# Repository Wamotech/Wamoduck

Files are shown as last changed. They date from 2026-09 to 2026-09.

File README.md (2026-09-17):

<p align="center">
  <a href="https://www.wamotechology.com">
    <picture>
      <source media="(prefers-color-scheme: dark)" srcset="assets/branding/wamotech-symbol-white.png">
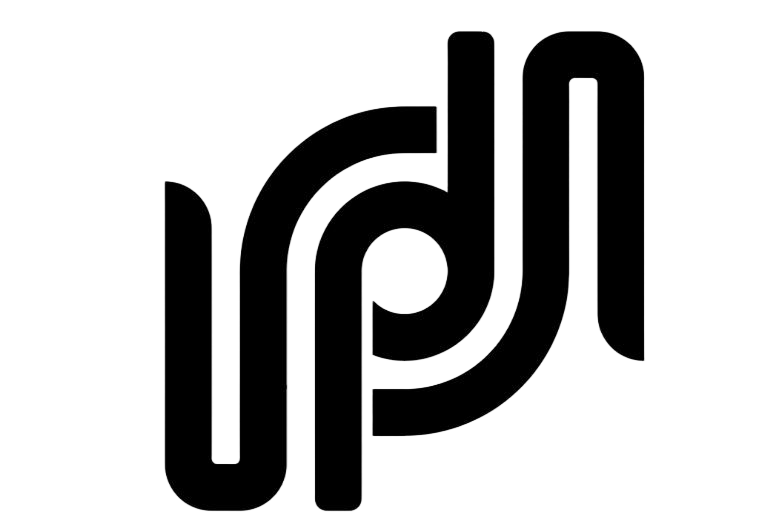
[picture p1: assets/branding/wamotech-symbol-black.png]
Wamotech logo
      
    </picture>
    <br>
    <picture>
      <source media="(prefers-color-scheme: dark)" srcset="assets/branding/wamotech-wordmark-white.png">
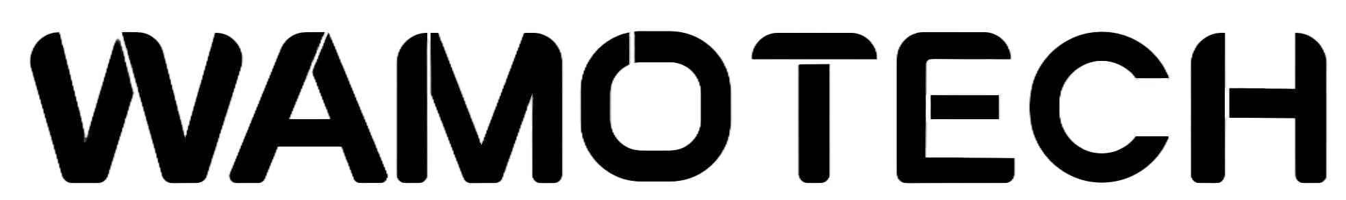
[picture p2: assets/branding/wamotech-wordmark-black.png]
WAMOTECH
      
    </picture>
  </a>
</p>

# Wamoduck

**An expressive little duck. A platform to explore motion, perception, and autonomous behavior.**

English | [简体中文](README.zh-CN.md)

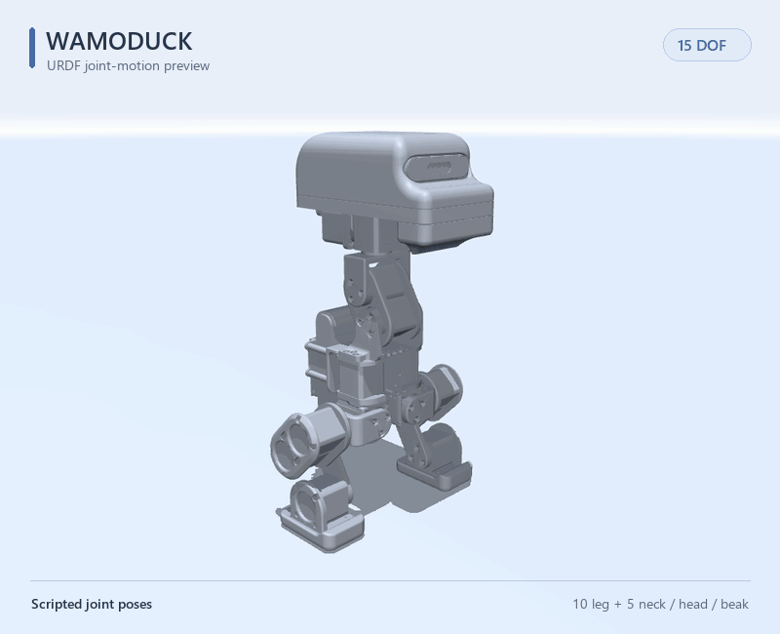
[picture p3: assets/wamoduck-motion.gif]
Wamoduck URDF joint-motion preview


*Rendered from the Wamoduck URDF. This scripted joint-motion preview illustrates articulation; it is not hardware footage or an ONNX policy rollout.*

## What this is

Wamoduck is a **15-DOF open-source biped duck robot**. Wamotech builds it as a small, approachable
platform for experimenting with motion, perception, and autonomous behaviour.

The project is in **mechanical prototyping and hardware/software integration**. The MuJoCo simulation
work is finished. The physical robot is still being assembled and debugged.

This repository is the public slice of that work. It gives you four things:

- the **CAD, URDF, and meshes** of the robot,
- a **reference walking gait** with a MATLAB player,
- **five trained policies** you can run yourself, in about five minutes,
- print files for a **standing fixture** and a small **display model**.

> ### Read this before you quote anything from here
>
> **Every result in this repository is a simulation result.** There is no hardware data anywhere in it,
> and no policy in it has ever been tested on a physical robot. "It stands in MuJoCo" is not a claim
> that it stands on the real machine.

**The quickest way in** is to run the policies. No GPU, no training framework, no MuJoCo experience.

## What it can do today, and what it cannot

Six behaviours were trained and measured in simulation on **2026-09-16**. Five of them ship here as ONNX
files you can run on your own machine.

| What it does | Policy | Measured result (simulation) |
| --- | --- | --- |
| Stands still, and takes a shove | `stand_v3` | Push threshold **40.5 N** — the smallest single horizontal 0.2 s shove that topples at least half of 64 environments. 40 N topples 45.3 % of them, and 0 to 24 N topples none. |
| Knocked down → gets up → back to the nominal stance | `stand_v3` + `getup_v20` | **5/5** end-to-end trials. "Did not fall again after standing up": **5/5**. |
| Gets up from a random lying pose | `getup_v20` | Standing at the end: **64/64**; strict "back to the saved nominal pose" **63/64 (98.4 %)** — up from **0/64**, with the largest joint deviation down from **52.3°** to **10.4°**. |
| Walks on flat ground | `walk_v4r` | Forward walking works. **Side-stepping does not**, and **in-place turning is out of reach for this mechanism** — a measured limit, not an unfinished training round. |
| Walks over 1 cm rough terrain | `rough_v2` | **51/64 (79.7 %)** survive 12 s at a 0.3 m/s command. Mean speed is **61 %** of the command. |
| Sits down and stands back up | `sit_stand_v3` | Interactive height control, and the two issues reported on the previous policy are **fixed**: standing jitter **0.699 → 0.000** and net drift **+27.99 → +0.394 mm/s**; the sitting pose goes from a **10.05°** lean with **146.09°** of left/right asymmetry to **0.225°** with a **0.473°** asymmetry. The seat is **0.11241 m** — 0.085 m is geometrically unreachable with an upright trunk. |

### What still does not work

- **In-place turning is out of reach for this mechanism, not merely untrained.** A 0.5 rad/s yaw command produced **+0.3°** of rotation in 10 s. Measured on plain CPU MuJoCo with both feet planted: the hips' yaw joints are an internal torque pair, so they can only twist the torso **±30.5°** relative to the ground, and unloading one foot would need a **60 mm** sideways CoM shift while the design can produce **38.5 mm** — at which point it is already tilted **28.5°** against a **30°** fall line. Eleven planted-foot drive patterns were tried; none accumulates. Measured with the published policy through the published runner, it **does not walk at all below 0.20 m/s** (0.012–0.018 m in 10 s at 0.10–0.15 m/s) and above that it turns **while moving** — 62 % / 69 % / 75 % of a 0.5 rad/s command at 0.20 / 0.30 / 0.40 m/s, on arcs of measured radius 0.72 / 0.93 / 1.11 m. The capability board therefore restates the deliverable as **turning while moving (tightest measured arc R ≈ 0.7 m at vx ≥ 0.20 m/s)** and lists true in-place rotation as a **hardware** change — see [Why in-place turning cannot be trained away](docs/capabilities.md#why-in-place-turning-cannot-be-trained-away).
- **Side-stepping drags the robot round.** A +0.30 m/s sideways command produced +0.218 m/s sideways
  *and* **+520.4°** of uncommanded yaw. Our own CPU run shows a small version of the same thing: over
  5 s of straight-ahead walking it drifted **0.328 m** sideways.
- **Get-up's "back to the nominal pose" gap was fixed on 2026-09-16.** On the **previous** policy
  (`getup_v18`, still published) it got up and stood reliably — 64/64 — but the strict criterion "back to the
  saved nominal pose" was **0/64**, with the error concentrated in the second link of the head chain
  (**52.3°** of joint deviation, and a sustained-900-step acceptance that stopped at `head_pitch` **46°**).
  The replacement `getup_v20` measures **63/64** on that strict criterion, **10.4°** of joint deviation, and
  **5/5** on the end-to-end hand-over. What changed was one reward term: the head-chain posture penalty is
  **ungated** and now weighs **−1.0**; gating it by body tilt — the previous round's change — let the policy
  escape through the gate by staying tilted, and it collapsed to **0/5** on the hand-over.
  The stricter six-axis criterion (head off the ground, flat soles, each sustained over the last second) is
  **45/64**, up from **0/64**.
- **Sit/stand was fixed on 2026-09-16, and the two problems remain on record with the measurements that
  found them.** On the **previous** policy (`sit_stand_v2`, still published): switching to `sitstand` made
  the robot **buzz in place while standing** — action jitter `mean abs(delta a)` per control step **0.235**
  at the 0.175 m command, against **2.9e-7** for `stand`, with **1.69 rad/s** of mean joint velocity that
  never decayed — and asking it to **sit** produced a **25.89°** lean (head **25.62°** off vertical) at
  **0.0943 m** instead of the 0.085 m commanded, resting partly on its own pelvis, with the left and right
  legs on opposite sides of zero on three of the five leg pairs (residuals **119°** to **174°**). The
  replacement policy `sit_stand_v3` measures **0.000** jitter, **+0.394 mm/s** of drift, and a sitting pose
  that is **0.225°** off vertical with a **0.473°** left/right residual — see [row 6 of the capability
  board](docs/capabilities.md#6-sit--stand). One limitation arrives with it: **the seated pose is not a
  stance the walking policy can start from** (tilt 134.9° after 6 s), so stand up with `m` before walking.
  Note also that the seat moved from 0.085 m to **0.11241 m**, because 0.085 m is geometrically unreachable
  with an upright trunk.
- **There is no hardware data at all.** Nothing in this repository was measured on a physical robot.

These are the parts we would rather state than let you discover. The full protocols, the tools behind
every figure, and the exact definition of "standing" are on the
[measured capability board](docs/capabilities.md) / [实测能力清单](docs/capabilities.zh-CN.md).

## Try it in 5 minutes

```bash
pip install mujoco onnxruntime numpy

git clone <this repository>
cd Wamoduck
python wamoduck_sim.py
```

One window opens, and all five policies run inside it. Press a number key to switch — and the window itself
tells you what the current policy does and which keys work for it, in plain words and in both languages:

| Key | Policy | What you should see |
| --- | --- | --- |
| `1` | `stand` — 站立抗推 | Standing still. Drag it with the mouse and it finds its balance again. |
| `2` | `getup` — 起身 | Starts lying on the ground, then stands up **and settles into the nominal pose**. |
| `3` | `sitstand` — 坐下与站起 | Press `m` to sit down (0.11241 m) and again to stand back up. |
| `4` | `walk` — 平地行走 | Arrow keys (or `w` `a` `s` `d`) drive it; `e` and `z` turn. Below 0.20 m/s it does not walk. |
| `5` | `rough` — 越障行走 | The same walking, over 1 cm curbs. It starts on three of them. |

The version handle (`getup_v20`, `sit_stand_v3`, …) is shown next to the plain name: it is what ties the file
you are running to a checkpoint, a hash and a changelog entry. Top-left in the window you get the policy, the
version, the keys that do something *for that policy*, and a suggested thing to try; bottom-left, the live
command values.

The runner needs only `mujoco`, `onnxruntime`, and `numpy` — no mjlab, no torch, no CUDA. A few useful
flags:

```bash
python wamoduck_sim.py --list                    # what is published
python wamoduck_sim.py --policy walk --vx 0.3    # start on walking at 0.3 m/s
python wamoduck_sim.py --policy getup --spawn lie-back
python wamoduck_sim.py --policy stand --check    # contract self-test, no window
```

**What our own CPU runs measured, through this same published code path:** `stand` holds **0.54°** of
tilt and 1 mm of drift over 5 s — good enough to pass even the strict nominal-stance criterion; `getup`
stands up from all five published lying poses within 6 s; and `walk` covers **1.482 m** of a commanded
**1.500 m** at 0.3 m/s.

Before you use the files, read the [simulation guide](docs/simulation.md) / [中文仿真指南](docs/simulation.zh-CN.md).
It writes out the observation layout and the action mapping item by item, explains why the ONNX already
contains the observation normalizer, explains why you **must** use the bundled MJCF and not the URDF, and
lists the known gaps.

## There is also a ROS 2 path

If you would rather not touch a physics engine, [`ros2/`](ros2/README.md) is a second way in. It is a
ROS 2 **Jazzy** chain for the same robot: the description loads in RViz, the reference gait replays as
`sensor_msgs/JointState`, and the 46-byte deployment protocol ships with a unit-tested, ROS-free codec.

Stage 1 (packages) and stage 2 (RViz visualisation) are built and verified. Read the
[ROS 2 guide](ros2/README.md) / [中文版](ros2/README.zh-CN.md) for the commands.

**What that path does not claim:**

| Area | State |
| --- | --- |
| Machine | Verified only on **WSL2 Ubuntu 24.04, x86_64**. Nothing has been built or run on the RDK X5's ARM64 userspace, so availability there is **unverified**. |
| Hardware | **Not verified.** No serial port, no CAN bus, no motors, no IMU. The protocol's `serial` transport has never been opened. |
| `policy_node` end to end | **Not run.** It is a skeleton: it assembles observations and never infers, because `onnxruntime` is not installed. |
| Gazebo and MoveIt | **Not started.** Nothing in `ros2/` runs Gazebo. |
| Physics | RViz integrates nothing and applies no gravity, so a gait that looks plausible on screen has proven nothing about dynamics or balance. **MuJoCo remains the physics reference for this project.** |

## Other ways to explore

### Try the reference gait in MATLAB

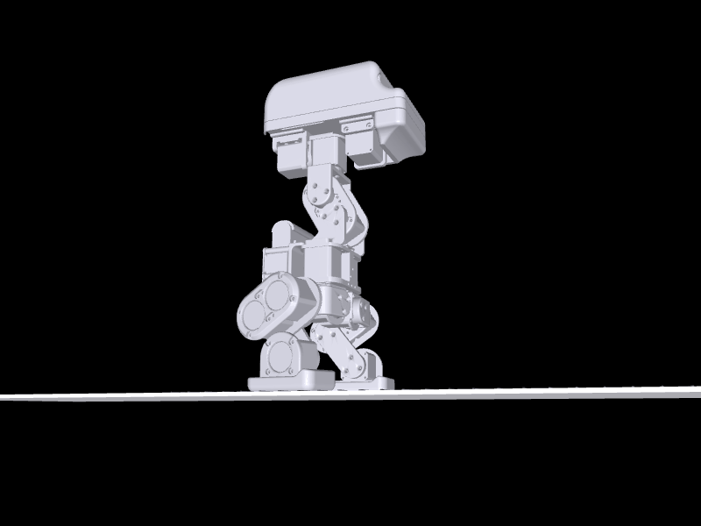
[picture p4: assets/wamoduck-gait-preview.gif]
Wamoduck walking reference gait


*Reference quasi-static gait, replayed from the public URDF by prescribing the joint angles in [tools/matlab/data/](tools/matlab/data/) and running forward kinematics. It is a plan, not a trained policy and not hardware footage.*

A walking reference trajectory for this URDF is included, together with a MATLAB player:

```matlab
cd <repo>              % the folder containing models/ and tools/
addpath('tools/matlab')
wamoduck_play          % interactive player
wamoduck_play(true)    % headless self-test: units, joint limits, ground contact
```

The player steps through the data, plots all 15 joint torques against the motor's rated and peak values,
and shows a per-joint angle/torque table. Two data sets ship with it: one steady-state gait cycle
(2.0 s, loops seamlessly) and the full 1 m walk.

The published CSV files contain model-computed joint angles and torque estimates. Their largest absolute
torque is **2.50815 N·m**, at the right knee in the full walk. The original higher-rate planner and its
IK/dynamics generation code are not included; see the [gait guide](docs/matlab.en.md) for the difference
between reproducible CSV checks and reported planning results.

The reference trajectory uses small alternating foot lifts. Its model-based playback does not establish
dynamic balance. The separate planning analysis identified limited lateral centre-of-mass travel and the
absence of an ankle roll; see the [gait guide](docs/matlab.en.md) for its scope and known limits.

### Print something

- The [standing calibration fixture](hardware/fixtures/standing-zero/README.md) has four printable parts,
  a two-plate H2D PLA project, six M3 screw specifications, and fitting instructions. Its digital
  geometry has been checked; **physical print fit and repeatability are still unmeasured**.
- The [160 mm A1 mini figurine](hardware/printable/wamoduck-a1mini-standing/README.md) is a separate
  single-piece display model.

### Open the CAD or the model

- [20 simplified STEP part models](hardware/step/) and the [native SolidWorks assembly](hardware/solidworks/)
  ([opening instructions](docs/mechanical.en.md#solidworks-assembly)).
- The [URDF and its meshes](models/wmduck/), with the [model guide](docs/model.en.md) for joint names,
  axes, and limits.
- The [component inventory](docs/components.md) for what the model actually contains.

Download or clone the complete repository before opening an assembly or URDF: those files need the parts
or meshes supplied alongside them.

### Wire it up

- The [CAN-FD bus IDs](hardware/motor_ids.md) of all 15 motors, with the position drawing, the three buses
  behind them, and the permutation from the policy's action vector to those IDs. The page also says plainly
  that the permutation and the bus topology have **not** been verified on the physical robot.

## Where to go next

| I want to… | Open |
| --- | --- |
| **Run the trained policies myself in MuJoCo** | [Simulation guide](docs/simulation.md) · [ONNX policies](policies/) · [`wamoduck_sim.py`](wamoduck_sim.py) |
| **Use ROS 2 instead of MuJoCo** | [ROS 2 guide](ros2/README.md) |
| See what the trained policies can actually do, and what still fails | [Measured capabilities](docs/capabilities.md) |
| Inspect or adapt individual mechanical parts | [20 STEP models](hardware/step/) · [Mechanical guide](docs/mechanical.en.md) |
| Print the standing calibration fixture | [Four parts + H2D PLA project](hardware/fixtures/standing-zero/README.md) · [Quantities](hardware/fixtures/standing-zero/print-parts.csv) |
| Print a small static display model | [160 mm A1 mini figurine](hardware/printable/wamoduck-a1mini-standing/README.md) |
| Look up a CAN-FD bus ID, or wire the three buses | [Bus IDs and the position drawing](hardware/motor_ids.md) |
| Explore the native assembly | [SolidWorks files](hardware/solidworks/) · [Opening instructions](docs/mechanical.en.md#solidworks-assembly) |
| View the robot and inspect its joints | [URDF and meshes](models/wmduck/) · [Model guide](docs/model.en.md) |
| Watch the reference gait / play with it in MATLAB | [Gait guide](docs/matlab.en.md) · [MATLAB player](tools/matlab/) · [Walk video](assets/wamoduck-gait-walk.mp4) |
| Understand the modeled components | [Component inventory](docs/components.md) |
| Help improve the project | [Contributing](CONTRIBUTING.md) · [Roadmap](docs/roadmap.md) |

## The robot itself

| Feature | What it enables |
| --- | --- |
| **Servo-based closed-loop control** | Motor feedback closes the loop between motion commands and execution, providing a basis for motion tracking and hardware tuning. |
| **A low-level “cerebellum” and a higher-level “brain”** | A 32-bit MCU handles low-level robot control, while an Arm-based computer supports ROS and ONNX policy inference. This separates motor control from higher-level perception and behavior. |
| **Onboard visual perception** | A binocular structured-light camera supplies visual and depth information for local scene recognition and spatial modeling. |
| **An extensible structure** | The mechanical design leaves room to adapt structures, sensors, and peripherals as experiments evolve, alongside changes to the computing and control stack. |

### System architecture

```mermaid
flowchart LR
    Remote[Remote-control commands] --> Brain["Arm brain<br/>ROS · ONNX policies<br/>Perception and behavior"]
    Camera["Binocular structured-light camera<br/>Visual and depth data"] --> Brain
    Brain <-->|Motion targets / state feedback| MCU["32-bit MCU cerebellum<br/>Low-level robot control"]
    MCU <-->|Commands / motor feedback| Servo[Servo motors]
```

This architecture is also being experimentally applied to **intelligent wearable robot projects**, exploring how control, perception, and policy components can be reused across different robot forms.

### 15 joints, from footsteps to expression

The finalized URDF describes **15 rotational DOF = 5 left-leg + 5 right-leg + 5 neck/head/beak**:

| Group | DOF | Joint sequence |
| --- | ---: | --- |
| Left leg | 5 | Hip yaw → hip roll → hip pitch → knee → ankle |
| Right leg | 5 | Hip yaw → hip roll → hip pitch → knee → ankle |
| Neck, head, and beak | 5 | Neck pitch → head pitch → head yaw → head roll → mouth |

The neck contributes 1 DOF, the head 3, and the beak 1. Together they allow expressive nods, turns, tilts, and beak movements in addition to the two leg chains.

There are **17 links**: 16 mechanical rigid bodies plus 1 fixed IMU reference link. The IMU reference does not add an actuated DOF. The saved standing pose is `q=0`, with bent legs and an inclined neck; it is not the motor encoder zero. See the [model guide](docs/model.en.md) for exact joint names, axes, and limits, and the [animation notes](assets/README.md) for how the preview was made.

<details>
<summary>Explore the 15 joint origins in four views</summary>

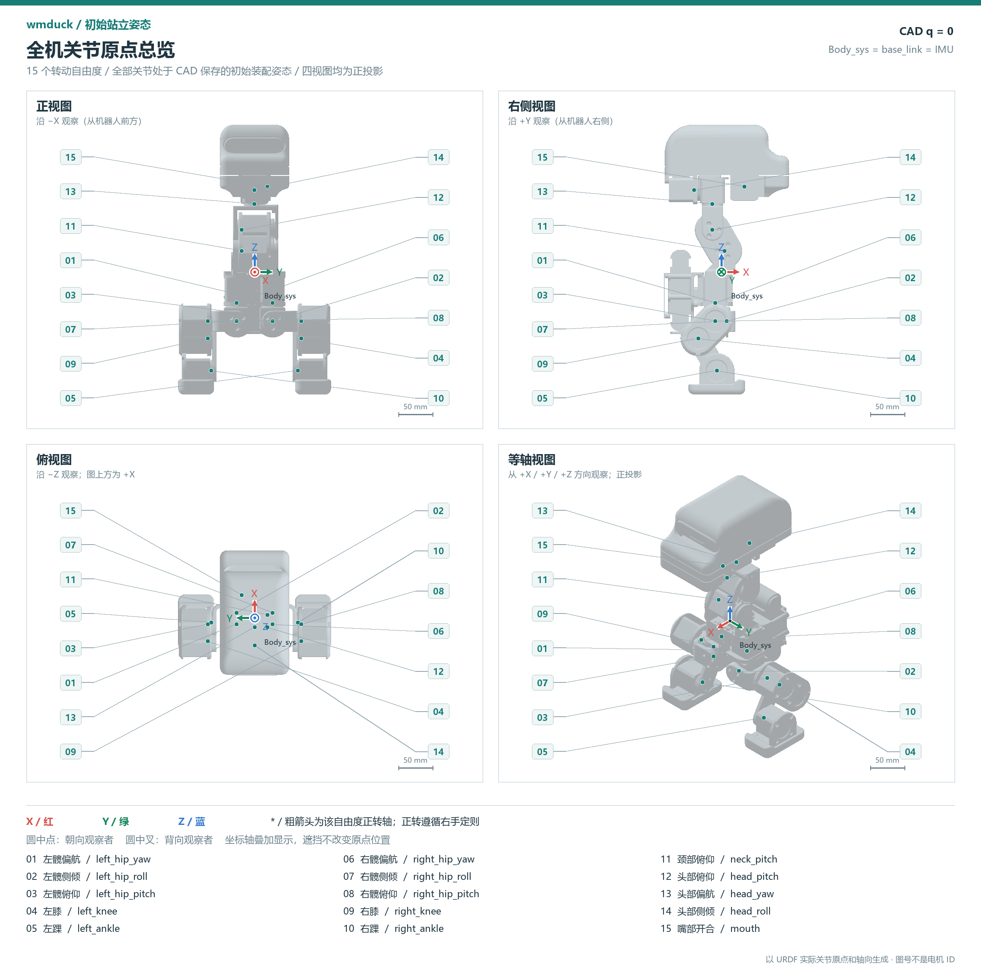
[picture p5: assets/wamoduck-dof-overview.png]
Final URDF joint-origin overview: front, right, top, and isometric views


Orthographic views of the finalized URDF at the saved `q=0` pose. Labels 01–05 identify the left leg, 06–10 the right leg, 11 the neck, 12–14 the head, and 15 the beak. These labels are diagram indices, not motor IDs. Red, green, and blue mark X, Y, and Z; the joint-name legend is included in the image.

</details>

## At a glance

| Item | Current model |
| --- | --- |
| Rotational joints | 15: left leg 5 + right leg 5 + neck/head/beak 5 |
| Robot description | URDF; 16 mechanical links + 1 fixed IMU reference link |
| Geometry | 20 simplified STEP part models; 20 STL meshes for the URDF |
| Approximate model envelope at the saved pose | 181.5 × 221.2 × 390.8 mm (X × Y × Z) |
| Estimated model mass | 3.751 kg; CAD values with a measured motor mass override, not a measured robot weight |
| Head-chain share of that mass | 1.654 kg = 44.1 %: `neck_pitch_link` through `mouth_link` |
| Model units | m, kg, rad; STEP files declare mm |

The mass and envelope describe the supplied model, not certified hardware specifications. See the [model assumptions](docs/model.en.md) before using its inertias, motor values, or joint ranges.

The behaviour table near the top of this page is a different kind of number: those rows are simulation
results for the trained policies, measured on 2026-09-16 in the private development environment. They are
**not hardware measurements.** Five of the policies are now published with a runner, so their behaviour
can be re-run here in simulation — see the [simulation guide](docs/simulation.md) for exactly what is and
is not reproducible — but the internal measurement protocols and tools are still private.
See [measured capabilities](docs/capabilities.md) for the methods, the tools, and the parts that do not work.

The bundled [validation record](models/wmduck/validation.json) covers this URDF package's structural and
import checks. It is not a validation of the project's simulation or of a physical robot.

## What is included

```text
Wamoduck/
├── hardware/
│   ├── step/             # Robot structure and purchased-component references, mm
│   ├── solidworks/       # Simplified native parts and assemblies
│   ├── robot-structure.csv # Geometry roles and modeled instance quantities
│   ├── motor_ids.md      # CAN-FD bus IDs, the three buses, and the action permutation
│   ├── fixtures/standing-zero/ # 4 STEP + 4 printable STL + H2D project
│   └── printable/        # Static display model and A1 mini project
├── models/wmduck/        # URDF, meshes, joint data, and import checks
│   └── mjcf/             # The MJCF models the policies were trained on
├── policies/             # Five trained ONNX policies
├── wamoduck_sim.py       # Single-file CPU runner: one demo, all five policies (mujoco + onnxruntime + numpy)
├── ros2/                 # ROS 2 Jazzy chain: description, nodes, RViz, the 46-byte protocol
├── tools/matlab/         # Reference-gait data and the MATLAB player
├── assets/              # Model preview, gait preview, and the motor-ID drawing
├── docs/                # Bilingual guides: mechanical, model, gait, simulation, capabilities, roadmap
├── CONTRIBUTING.md
└── LICENSE
```

Robot STEP files support geometry exchange and slicing of the selected structural geometry. The [manufacturing map](hardware/robot-structure.csv) distinguishes structural parts from motors, bearings, and electronics supplied as assembly references. The STL files under `models/wmduck/meshes/` use meters for robot visualization and collision; use the millimeter STL files in [the fixture package](hardware/fixtures/standing-zero/README.md) to print the jig. Joint limits are estimates from single-joint geometry checks and do not guarantee collision-free combined motion.

## What this repository does not contain yet

The simulation and training code, the checkpoints behind the measured results and their evaluation tools,
the runtime software, the electronics, and a complete build guide are **not** published here. Neither is a
verified procurement BOM, structural manufacturing specification, assembly instruction, wiring diagram, or
control software.

A complete working robot needs all of those. The [roadmap](docs/roadmap.md) tracks them as deliverables.

## Build along with us

Interested in servo control, robot perception, policy deployment, or your own mechanical variation? **Star the project to follow its progress**, share ideas through Issues, or contribute improvements through a pull request. Contributions in English and Chinese are welcome; start with the [contribution guide](CONTRIBUTING.md).

We will keep publishing mechanical revisions, integration progress, and software and hardware documentation as the project develops. Follow the [roadmap](docs/roadmap.md) for the next steps.

## Contact

- Email: [business@wamotechology.com](mailto:business@wamotechology.com)
- Website: [www.wamotechology.com](https://www.wamotechology.com)

## References and license

The documentation structure draws on [Open Duck Mini](https://github.com/apirrone/Open_Duck_Mini) and [Pollen Robotics Microduck](https://github.com/pollen-robotics/microduck): accessible design files, clear model assumptions, and separate build/runtime/training instructions. The ONNX deployment approach is similar in spirit to [Microduck](https://github.com/pollen-robotics/microduck) and [microduck_rl](https://github.com/pollen-robotics/microduck_rl). See [references and scope](docs/references.md) for the exact sources and distinctions.

This repository retains its existing [MIT license](LICENSE), copyright © 2026 Wamotech. Referenced projects and third-party components retain their own licenses and rights. Their dimensions, controllers, and build instructions should not be assumed compatible with Wamoduck.

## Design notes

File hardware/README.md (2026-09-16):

# Mechanical design / 机械设计

[English guide](../docs/mechanical.en.md) · [中文指南](../docs/mechanical.zh-CN.md)

[Static display prints / 固定展示打印模型](printable/README.md): a separate 160 mm A1 mini figurine, with fused joints and an integral base. / 独立的 160 mm A1 mini 摆件，关节固定并带一体底座。

- [step/](step/): 20 simplified millimetre STEP geometries: 15 robot-structure classes and 5 purchased/reference classes. See [robot-structure.csv](robot-structure.csv). / 20 类毫米单位 STEP 简化几何：15 类机器人结构几何与 5 类外购／参考几何，分类见 [robot-structure.csv](robot-structure.csv)。
- [solidworks/](solidworks/): 20 parts and 11 assemblies; start with `Full_wmduck.SLDASM`. / 20 个零件与 11 个装配体，入口为 `Full_wmduck.SLDASM`。
- [fixtures/standing-zero/](fixtures/standing-zero/): downloadable standing-zero calibration fixture with [English](fixtures/standing-zero/README.md) and [中文](fixtures/standing-zero/README.zh-CN.md) instructions. It contains four editable STEP files, four millimetre-scale print STL files, and a user-supplied Bambu H2D 3MF arranged on two plates. Print one of each part; assembly uses six M3 screws. / [站姿零点标定工装](fixtures/standing-zero/)提供[英文](fixtures/standing-zero/README.md)与[中文](fixtures/standing-zero/README.zh-CN.md)说明，包含 4 个可编辑 STEP、4 个毫米单位打印 STL，以及用户提供的双盘 Bambu H2D 3MF。每种零件打印 1 件，共使用 6 颗 M3 螺钉。
- [motor_ids.csv](motor_ids.csv) with [English](motor_ids.md) and [中文](motor_ids.zh-CN.md) notes: the CAN-FD bus ID of each of the 15 motors, which of the three buses (left leg, right leg, neck and head, each on an XT30(2+2) connector carrying power and CAN-FD) that motor sits on, and the permutation from the policy's 14-dimension action vector to those IDs. Bus IDs, joint names, and orders are interface facts; the page carries a prominent warning that the permutation and the bus topology are unverified on the physical robot. / [motor_ids.csv](motor_ids.csv) 及[英文](motor_ids.md)、[中文](motor_ids.zh-CN.md)说明：15 个电机各自的总线 ID、它挂在哪一路总线（左下肢、右下肢、脖子及头部，每路用承载电源与 CAN-FD 的 XT30(2+2) 端子），以及从策略 14 维动作向量到这些 ID 的置换。总线 ID、关节名与顺序都是接口事实；该页醒目地警告：置换与总线拓扑均未在实机上验证。

The 20 robot STEP/native files provide geometry and assembly references; their assembly instance counts do not define printable part splits. `Body_Frame` may import as multiple bodies, and CAD material labels are model metadata rather than manufacturing requirements. Manufacturing and clean-session native dependency validation for the robot are still pending. The zero fixture has passed the documented CAD/STL checks, but no physical print or repeatability test is claimed. / 这 20 类机器人 STEP／原生文件用于几何和装配参考；装配实例数量不等于打印分体数量。`Body_Frame` 导入后可能包含多个实体，CAD 材料标签属于模型元数据，不是制造要求。机器人制造要求及原生装配在独立会话中的依赖验证仍待补齐。零点工装已通过文档所列 CAD／STL 检查，但不宣称已经完成实物打印或重复定位测试。

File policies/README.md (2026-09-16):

# Wamoduck policies / 策略权重

[English simulation guide](../docs/simulation.md) · [中文仿真指南](../docs/simulation.zh-CN.md)

Five trained tasks, and six ONNX actors: the sit/stand row carries **two** files, because the 2026-09-16
replacement is published next to the file whose measured problems it fixes. Each is an ONNX actor for one
task; run them with [`wamoduck_sim.py`](../wamoduck_sim.py) and the MJCF in
[`models/wmduck/mjcf/`](../models/wmduck/mjcf/). / 五个训练任务、**六个** ONNX actor：坐／站那一行有**两份**
文件 —— 2026-09-16 的替换版本与"被它修掉的那两个实测问题所属的旧版"一起保留。每个都是某一任务的
ONNX actor；请配合 [`wamoduck_sim.py`](../wamoduck_sim.py) 与
[`models/wmduck/mjcf/`](../models/wmduck/mjcf/) 里的 MJCF 运行。

| File / 文件 | Bytes | SHA-256 | Source run / 来源轮次 | Checkpoint / 检查点 | Task / 任务 |
| --- | ---: | --- | --- | --- | --- |
| [wamoduck-stand-stand_v3.onnx](wamoduck-stand-stand_v3.onnx) | 766915 | `3ec3397ae9c17743ee4214234864da392562f7550ca7459ef1bd09dd2f44262f` | `2026-09-12_08-32-26_stand_v3` (SHIP) | `model_1499.pt` | stand / 站立抗扰 |
| [wamoduck-getup-getup_v18.onnx](wamoduck-getup-getup_v18.onnx) | 766915 | `804d2cee90881d6eb4756f9306d27bd3e19c8e9aa3f903bec65089787e323bf5` | `2026-09-15_17-37-06_getup_v18` | `model_3999.pt` | get up — **superseded, kept for the measurements below** / 起身 —— **已被取代**，保留用于复现那些测量 |
| [wamoduck-getup-getup_v20.onnx](wamoduck-getup-getup_v20.onnx) | 766915 | `29bbebd0d6597a1f425305c90fc29a1b71c79e066a26ae44c20e1fab3a3fbed6` | `2026-09-16_19-12-01_getup_v20` | `model_3999.pt` | get up — **current**; returns to the nominal stance / 起身 —— **当前版**；能站回标称姿态 |
| [wamoduck-sitstand-sit_stand_v2.onnx](wamoduck-sitstand-sit_stand_v2.onnx) | 768992 | `26e40f7a20f333c52816e53cb092b945f677c526d8f1685bf886d321c21a680d` | `2026-09-12_11-18-34_sit_stand_v2` (SHIP) | `model_2499.pt` | sit / stand — **superseded, kept for the measurements below** |
| [wamoduck-sitstand-sit_stand_v3.onnx](wamoduck-sitstand-sit_stand_v3.onnx) | 768992 | `c75139732aa2890964f56a5df78b8c8c351d2fea88533ac5b1fb78aba6574163` | `2026-09-16_18-05-44_sit_stand_v3` | `model_2499.pt` | sit / stand — **current**; fixes both problems measured on v2 |
| [wamoduck-walk-walk_v4r.onnx](wamoduck-walk-walk_v4r.onnx) | 773096 | `8ec4fd347a22d69937550681e58e6d2cd511748b067677bcef345fdae5546ea2` | `2026-09-16_12-01-21_walk_v4r` | `model_6749.pt` | walking / 平地行走 |
| [wamoduck-rough-rough_v2.onnx](wamoduck-rough-rough_v2.onnx) | 773096 | `811d79ea78a0ba3d349f5b7709fe6ffaf382c3929d61b13f47b43a0fac4a425b` | `2026-09-16_00-00-04_rough_v2` | `model_5999.pt` | 1 cm terrain / 1 cm 越障 |

The runs were resolved with the development repository's `tools/run_select.py`, not by picking a file by
hand. Each published file was then confirmed to be the export of exactly the checkpoint named above, by
rebuilding the actor from the `.pt` file and comparing it with the ONNX initializers. That comparison is a
tool, not a one-off: `tools/verify_onnx_provenance.py --onnx <file> --run <run> --expect <checkpoint>`
reports the exact match over every `model_*.pt` in the run and exits non-zero otherwise (its `--selftest`
proves the criterion accepts the right checkpoint and rejects a perturbed one). For a byte-identical
export the element-wise difference is exactly zero, which is what all five rows above report. / 轮次是用研发
仓库的 `tools/run_select.py` 解析出来的，不是手工挑的文件。随后每个公开文件都用 `.pt` 重建 actor 与 ONNX 权重逐项
比对，确认它确实就是上表写明的那个检查点导出的。这个比对已经做成了工具（见上），它对轮次目录里的每个
`model_*.pt` 报出精确匹配、否则以非零码退出；导出是纯拷贝，所以逐元素差**恰好为 0** —— 上表五行都满足。

> **A note on the walking row / 关于行走那一行**：this file was first published as `model_6000.pt`, taken
> from the run directory while training was **still running** — mjlab rewrites that directory's ONNX on
> every checkpoint save, so the copy captured a mid-run save and the run's final save (`model_6749.pt`,
> written 28 minutes later) never reached this repository. It has been replaced with the run's final
> checkpoint; both revisions are valid exports of the same run, and the file now matches the checkpoint
> this table names. Lesson recorded because it is a repeatable trap: **do not publish from a directory
> whose training is still in progress**, and verify provenance instead of trusting the file name. / 这个文件
> 最初是以 `model_6000.pt` 发布的：当时训练**还在跑**，而 mjlab 在每次保存检查点时都会重写轮次目录里的那份
> ONNX，所以拷走的是中途某一次保存，训练结束时（28 分钟后写入的 `model_6749.pt`）从未进过本仓库。现在已换成
> 该轮次的最终检查点；两版都是同一轮次的合法导出，只是现在这个文件与上表写明的检查点一致。把教训写在这里，
> 因为它是可复现的坑：**不要在训练还在进行时发布**，并且要核验来源，不要相信文件名。

> **A note on the sit/stand row / 关于坐／站那一行**：`sit_stand_v3` replaces `sit_stand_v2` and fixes both
> problems that the capability board measured on it. Standing jitter `mean|Δa|` **0.699 → 0.000** and net
> drift **+27.99 → +0.394 mm/s**; the sitting pose goes from a **10.05°** lean at 0.112 m (and **25.91°** at
> the old 0.085 m command) with left/right residuals of **146.09°** / **173.56°**, to a **0.225°** lean with
> a **0.473°** residual between the two legs. The seat is now **0.11241 m**, not 0.085 m: 0.085 m is
> **geometrically unreachable** while the trunk is upright, because the torso collision box's lowest corner
> sits **109 mm** below the base origin — the old policy only "reached" 0.094 m by leaning 25.9° to lift that
> corner clear of the floor. One measured limitation comes with the new pose: **switching to `walk` while
> seated collapses the robot** (tilt 134.9° after 6 s), because the walking policy has never seen a seated
> stance — press `m` first, which is what the bundled runner's self-test now does. / **`sit_stand_v3` 取代
> `sit_stand_v2`，修掉能力清单在旧版上实测到的两个问题**：站立抖动 `mean\|Δa\|` **0.699 → 0.000**、净漂移
> **+27.99 → +0.394 mm/s**；坐姿从"指令 0.112 m 时倾 **10.05°**（旧指令 0.085 m 时 **25.91°**）、左右腿残差
> **146.09°／173.56°**"变成"倾 **0.225°**、左右残差 **0.473°**"。坐高改为 **0.11241 m** 而不是 0.085 m：
> 躯干直立时 0.085 m **几何不可达** —— 躯干碰撞盒最低角点在基座原点下方 **109 mm**，旧策略能凑到 0.094 m
> 是靠歪 25.9° 把那个角抬离地面。新坐姿带来一条实测限制：**坐着直接切到 `walk` 会让机器人瘫倒**
> （6 s 后倾角 **134.9°**），因为行走策略从未见过坐姿 —— 先按 `m` 站起来，随仓库的运行器自检现在就是这么做的。

> **A note on the get-up row / 关于起身那一行**：`getup_v20` replaces `getup_v18` and closes the gap the
> capability board measured on it. Recovering from a random lying pose: standing at the end **64/64**,
> time to first standing **0.48 s** median, final tilt **2.5°**; the strict criterion "back to the saved
> nominal pose" goes **0/64 → 63/64 (98.4 %)** with the largest joint deviation **52.3° → 10.4°**, and the
> end-to-end hand-over (shoved over → gets up → back to nominal) is **5/5** with **5/5** "did not fall again"
> (v18 was 4/5 on that last row). The only change was in the reward: the head-chain posture penalty was
> **ungated** and its weight went **−0.5 → −1.0**; the previous round had gated it by body tilt, and the
> policy escaped through the gate by staying tilted — see the [changelog](../CHANGELOG.md). The stricter
> six-axis criterion (which also requires the head to stay off the ground and the soles to be flat, sustained
> over the last second) is **206/256 (80.5 %)** at 256 environments, up from **0/64** — reported with the
> 64-environment figure of **45/64** alongside it, because the per-axis rates are the stable part
> (tilt 239/256, both feet 221/256 — read through a contact path this project has flagged as unreliable,
> 245/256 there against 256/256 from the contact sensors — joint deviation 237/256, base height 255/256,
> head off the ground 253/256, flat soles 209/256) and the all-six conjunction is sample-limited. v18 is kept
> so the measurements above stay reproducible. / **`getup_v20` 取代 `getup_v18`，
> 补上了能力清单在旧版上实测到的那条差距**：随机躺姿起身 —— 末态站住 **64/64**、首次站起时间中位
> **0.48 s**、末态倾角 **2.5°**；严格口径"回到保存的标称姿态" **0/64 → 63/64（98.4 %）**，最大关节偏差
> **52.3° → 10.4°**；端到端接力（推倒→起身→站回标称）**5/5**，其中"起身后没有再次摔倒"**5/5**（v18 在这一行
> 是 4/5）。唯一的改动在奖励侧：头链姿态惩罚**不加门控**、权重由 **−0.5 改到 −1.0** —— 上一轮给它加了"按
> 身体倾角生效"的门，结果策略靠**一直歪着**从门里逃了出去（见[更新记录](../CHANGELOG.md)）。更严的六轴
> 口径（还要求头不压地、脚掌平贴，并要求在最后一秒内持续成立）从 **0/64** 升到 **45/64**，逐轴为
> 56/64、52/64、58/64、61/64、61/64、46/64。v18 保留，好让上面的测量可复现。

## Contract / 契约

| Item / 项目 | Value / 取值 |
| --- | --- |
| ONNX input / 输入 | `obs`, float32, `[1, N]` with N = 48 / 49 / 51 |
| ONNX output / 输出 | `actions`, float32, `[1, 14]` |
| Control rate / 控制频率 | 50 Hz (`decimation = 4` × `timestep = 0.005 s`) |
| Observation normalizer / 观测归一化 | **Inside the ONNX** — feed raw observations, never normalize again / **已含在 ONNX 内** —— 喂原始观测，绝不要再归一化 |
| Action → target / 动作换算 | `q_target = default_joint_pos + 1.0 × action`, `default_joint_pos` is 14 zeros / 为 14 个 0 |
| Action clipping / 动作截断 | none in the policy; MuJoCo clamps `ctrl` to `ctrlrange` / 策略侧无截断；MuJoCo 按 `ctrlrange` 截断 |
| Joint order / 关节顺序 | joint-tree order (left leg, then right leg, then neck/head) — **not** the MJCF actuator order / 关节树顺序，**不是** MJCF 执行器顺序 |

The full observation layout, offsets, and the evidence behind the joint-order and normalizer statements are
on the [simulation page](../docs/simulation.md) / [仿真页](../docs/simulation.zh-CN.md).

## Verify them yourself / 自己验一遍

```bash
python wamoduck_sim.py --check --policy stand      # also: getup, sitstand, walk, rough
```

This checks the ONNX input/output shape against the task contract, re-derives the observation blocks against
MuJoCo, and confirms the graph contains the normalizer.

## Scope / 范围

These files are the trained actors, published so the policies can be run and inspected. They are **not** a
hardware deployment package: motor calibration, encoder signs and zeroes, CAN IDs, timing, and safety limits
are not solved here, and no policy in this repository has been validated on a physical robot. / 这些文件是训练
出来的 actor，公开出来是为了让策略能被运行与检查。它们**不是**硬件部署包：电机标定、编码器方向与零位、CAN ID、
时序与安全限幅都没有在这里解决，本仓库里的任何策略都没有在实物机器人上验证过。

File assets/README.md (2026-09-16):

# Visual assets / 图像与动图

[English home](../README.md) · [中文首页](../README.zh-CN.md)

| Asset / 文件 | Contents / 内容 |
| --- | --- |
| [Brand logo](branding/wamotech-symbol-black.png) · [White version](branding/wamotech-symbol-white.png) | Maintainer-supplied Wamotech symbol, copied unchanged / 维护者提供的望默科技图形标志，原样复制 |
| [Wordmark](branding/wamotech-wordmark-black.png) · [White version](branding/wamotech-wordmark-white.png) | WAMOTECH wordmark paired with the symbol in both README headers / 与图形标志配套展示在中英文首页的 WAMOTECH 字标 |
| [wamoduck-motion.gif](wamoduck-motion.gif) | Animated joint-motion preview rendered from the public URDF / 由公开 URDF 渲染的关节运动演示 |
| [wamoduck-push-normal.gif](wamoduck-push-normal.gif) | An ordinary push while standing; the robot stays on its feet (simulation) / 平常推一把：没倒（仿真） |
| [wamoduck-pushed-down-recover.gif](wamoduck-pushed-down-recover.gif) | Pushed over, then recovers to the nominal stance (simulation) / 被推倒后自己站回标称姿态（仿真） |
| [wamoduck-getup-struggle.gif](wamoduck-getup-struggle.gif) | The hardest case: repeated attempts, finally gets up (simulation) / 最剧烈的一段：连续尝试、最终成功起身（仿真） |
| [wamoduck-force-test-demo.mp4](wamoduck-force-test-demo.mp4) | Full-length recording of the same session, 1:49.37 (simulation) / 同一场次的全长录像，1:49.37（仿真） |
| [wamoduck-gait-preview.gif](wamoduck-gait-preview.gif) | Reference walking gait, two cycles, rendered from the public URDF / 参考行走步态（两个周期），由公开 URDF 渲染 |
| [wamoduck-gait-walk.mp4](wamoduck-gait-walk.mp4) | The same gait, 20 s of continuous walking with the body position shown / 同一步态，连续行走 20 s 并标出机体位置 |
| [wamoduck-gait-still.png](wamoduck-gait-still.png) | Single frame of the reference gait / 参考步态的单帧静图 |
| [wamoduck-matlab-player.png](wamoduck-matlab-player.png) | Screenshot of the bundled MATLAB player / 随仓库附带的 MATLAB 回放器截图 |
| [wamoduck-dof-overview.png](wamoduck-dof-overview.png) | Four-view joint-origin overview from the finalized URDF export / 最终 URDF 导出的四视图关节原点总览 |
| [wamoduck-motor-ids.png](wamoduck-motor-ids.png) | Motor position drawing with the CAN-FD bus ID of each motor / 标出每个电机 CAN-FD 总线 ID 的位置图 |
| [wamoduck-model.png](wamoduck-model.png) | Original static model rendering at the saved pose / 原有保存姿态下的静态模型渲染 |
| [media-manifest.json](media-manifest.json) | Provenance, hashes, and animation properties for the added media / 新增图像的来源、哈希与动图属性 |

## Motion preview / 运动演示

The animation uses the geometry and joint definitions in [wmduck.urdf](../models/wmduck/wmduck.urdf). Preset joint angles are applied and rendered with MuJoCo forward kinematics. It demonstrates the articulated model, including both legs and the neck/head/beak chain; the movements are not produced by a trained ONNX policy or a physical robot. / 动图使用 [wmduck.urdf](../models/wmduck/wmduck.urdf) 的几何与关节定义，设置预定关节角并通过 MuJoCo 前向运动学渲染，展示双腿以及颈部、头部、嘴部的结构运动；动作并非由训练后的 ONNX 策略或实物机器人产生。

All animated joint values remain within the supplied URDF ranges. This is a visualization check, not a dynamic balance or collision-clearance test. Presentation changes such as lighting and camera settings do not change the published CAD or URDF. / 动画关节值保持在所附 URDF 范围内；这属于可视化检查，不是动态平衡或碰撞间隙验证。灯光、相机等展示设置不改变公开 CAD 或 URDF。

## Reference gait / 参考步态

[wamoduck-gait-preview.gif](wamoduck-gait-preview.gif) and [wamoduck-gait-walk.mp4](wamoduck-gait-walk.mp4) replay the **reference quasi-static gait** supplied in [tools/matlab/data/](../tools/matlab/data/): the same URDF, the same method as the joint-motion preview — prescribed joint angles plus MuJoCo forward kinematics, with the body pose from the data file. The GIF covers two whole cycles (the ground tick spacing equals one cycle's 2 cm of travel, so the loop is seamless). / [wamoduck-gait-preview.gif](wamoduck-gait-preview.gif) 与 [wamoduck-gait-walk.mp4](wamoduck-gait-walk.mp4) 回放的是 [tools/matlab/data/](../tools/matlab/data/) 里的**参考准静态步态**：同一个 URDF、与关节运动演示相同的方法（给定关节角 + MuJoCo 前向运动学），机体位姿取自数据文件。GIF 覆盖两个整周期（地面刻度间距等于一个周期的 2 cm 前进量，因此循环无缝）。

The gait is an inverse-kinematics plan with a static-stability check: 1 cm per step, 1 cm/s, 4.5 mm foot lift, peak inverse-dynamics torque 2.53 N·m. It is **not** a trained policy, **not** hardware footage, and **not** a dynamic-balance result; the scripted-motion note above applies in full. / 该步态是带静态稳定性检查的逆运动学规划：每步 1 cm、1 cm/s、抬脚 4.5 mm、逆动力学峰值力矩 2.53 N·m。它**不是**训练策略、**不是**实物拍摄、**也**不是动态平衡结果；上面关于"预定动作"的说明完全适用。

[wamoduck-matlab-player.png](wamoduck-matlab-player.png) is a screenshot of [tools/matlab/wamoduck_play.m](../tools/matlab/wamoduck_play.m) playing the same data set. See the [gait guide](../docs/matlab.en.md) / [步态指南](../docs/matlab.zh-CN.md) for the measured numbers and the known limits. / [wamoduck-matlab-player.png](wamoduck-matlab-player.png) 是 [tools/matlab/wamoduck_play.m](../tools/matlab/wamoduck_play.m) 回放同一份数据的截图。实测数据与已知限制见[步态指南](../docs/matlab.zh-CN.md)。

## DOF overview / 自由度总览

The overview is copied unchanged from the finalized model's `coordinate_frames/00_overview.png`. It shows front, right, top, and isometric orthographic views at the saved CAD pose (`q=0`). Labels 01–15 are diagram indices, not motor IDs. / 总览图原样取自最终模型的 `coordinate_frames/00_overview.png`，包含 CAD 保存姿态（`q=0`）下的正视、右侧视、俯视与等轴正投影视图。01–15 是图册索引，不是电机 ID。

The 15 joint definitions in the public URDF match the finalized export. Current joint ranges were retained; their confirmation does not imply a new measurement of physical stops or encoder offsets. See the [English model guide](../docs/model.en.md) / [中文模型指南](../docs/model.zh-CN.md). / 公开 URDF 的 15 个转动关节定义与最终导出一致，沿用已确认的关节范围；确认模型参数不代表重新实测了机械挡位或编码器零偏，详见模型指南。

## Motor ID position drawing / 电机 ID 位置图

[wamoduck-motor-ids.png](wamoduck-motor-ids.png) is the maintainer's motor-position drawing, exported unmodified from the single slide of the position deck. Two CAD views show the same robot, with the CAN-FD bus ID printed beside each of the 15 motors and `Left` / `Right` written under the legs. The two CAD renders embedded in that deck carry no IDs by themselves; the numbers are text shapes drawn over them, which is why an export of the slide is published rather than an extracted image. The source deck is **not** redistributed. See the [bus ID notes](../hardware/motor_ids.md) / [中文总线 ID 说明](../hardware/motor_ids.zh-CN.md) for the mapping, and for the warning that the permutation and the bus topology are unverified on the physical robot. / [wamoduck-motor-ids.png](wamoduck-motor-ids.png) 是维护者的电机位置图，从位置幻灯片的唯一一页原样导出。两个 CAD 视图是同一台机器人，15 个电机旁边各标着它的 CAN-FD 总线 ID，腿部下方写着 `Left` / `Right`。该幻灯片里内嵌的两张 CAD 渲染图本身不带 ID；数字是叠在它们之上的文本框，所以这里公开的是"把这一页导出"，而不是抽出来的某张内嵌图。源幻灯片**不**随本仓库分发。映射表，以及"置换与总线拓扑尚未在实机上验证"的警告，见[总线 ID 说明](../hardware/motor_ids.zh-CN.md)／[英文](../hardware/motor_ids.md)。

## Trained-policy simulation clips / 已训练策略的仿真演示

Unlike the kinematic previews above, these four clips are **screen recordings of the MuJoCo simulation running this project's trained policies** — `stand_v3` for standing against pushes and `getup_v18` for getting up — not prescribed joint angles. **They are simulation, not hardware footage:** no physical robot appears in them. Each clip is one selected take that shows the behaviour; the measured rates, the protocols behind them, and the parts that still fail are in the [measured capability board](../docs/capabilities.md) / [实测能力清单](../docs/capabilities.zh-CN.md). The clips were recorded before 2026-09-16: the get-up policy has since been replaced by `getup_v20` (which returns to the nominal stance) and the sit/stand policy by `sit_stand_v3`, so the get-up clips show the earlier policy — the media manifest names the checkpoint each recording used. / 与上面几段运动学预览不同，这四段是**仿真录屏**：跑的是本项目训练出来的策略 —— 站立抗扰 `stand_v3`、起身 `getup_v18` —— 而不是预设关节角。**它们是仿真，不是实机录像**：画面里没有实物机器人。每段都是挑选出来的单次片段，只用来展示这个行为；实测比例、测量协议与仍不可用的部分见[实测能力清单](../docs/capabilities.zh-CN.md)。这些片段录于 2026-09-16 之前：此后起身策略换成了 `getup_v20`（能站回标称姿态）、坐／站策略换成了 `sit_stand_v3`，所以起身那几段展示的是更早的策略；每段录像用的检查点在媒体台账里写明。

The training-progress overlay ball that was visible in the original screen capture has been removed from all four clips; the published files are **not** the untouched original recording. After removal, the same bright-green detector that finds the ball reports **0 pixels**, and the magenta chroma-key residue that the capture left in the top-right corner of every frame was repainted from neighbouring ground pixels (0 magenta pixels measured afterwards). That corner is therefore repaired, not recorded. / 原始录屏里可见的「训练进度悬浮球」已从这四段里移除，公开文件**不是**未经处理的原始录屏。移除后，用于定位悬浮球的同一套亮绿检测在输出上给出 **0 像素**；录屏留在每帧右上角的品红抠图色块，也用相邻地面像素修补过（修补后测得 0 个品红像素）。也就是说，右上角是修补出来的，不是录进去的。

| Clip / 片段 | Shows / 内容 | Simulation time covered / 覆盖的仿真时间 |
| --- | --- | --- |
| [wamoduck-push-normal.gif](wamoduck-push-normal.gif) | An ordinary push — it stays on its feet / 平常推一把：没倒 | 0–7 s |
| [wamoduck-pushed-down-recover.gif](wamoduck-pushed-down-recover.gif) | Pushed over, then recovers to the nominal stance / 被推倒后自己站回标称姿态 | 1:23–1:30 |
| [wamoduck-getup-struggle.gif](wamoduck-getup-struggle.gif) | The hardest case: repeated attempts, finally gets up / 最剧烈的一段：连续尝试、最终成功起身 | 16–50 s |
| [wamoduck-force-test-demo.mp4](wamoduck-force-test-demo.mp4) | The same session at full length, 1280 × 716, 30 fps, no audio / 同一场次的全长录像，1280 × 716、30 fps、无音轨 | 0–1:49.37 |

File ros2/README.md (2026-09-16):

# Wamoduck on ROS 2 (Jazzy)

A ROS 2 chain for the Wamoduck (`wmduck`) 15-DoF biped, aimed at people who are **not**
fluent in MuJoCo: install, build, launch, and see the robot move — without touching the
physics stack.

**Scope of this directory: the first two stages only.**

| Stage | Contents | State |
| --- | --- | --- |
| **1. Description + nodes** | `wamoduck_msgs`, `wamoduck_description`, `wamoduck_ros2` | done, built and verified (see [Verification status](#verification-status)) |
| **2. RViz visualisation** | `display.launch.py`, `gait_display.launch.py`, two `.rviz` configs | done, screenshot evidence in [`verification/`](verification/) |
| 3. Gazebo | `ros-jazzy-ros-gz`, physics, controllers | **not started — nothing here runs Gazebo** |
| 4. MoveIt | motion planning | **not started** |

Nothing in this directory claims Gazebo or MoveIt works. Nothing here claims anything about
real hardware, and `ros-jazzy-ros-gz` is deliberately not a dependency.

> **Stage 2 has no physics.** RViz integrates nothing, collides nothing and applies no
> gravity. A gait that looks plausible on screen has proven that the description loads, that
> the joint frames are where the URDF says they are, and that a `JointState` stream is well
> formed. It has proven nothing about dynamics or balance. MuJoCo remains the physics
> reference for this project.

---

## Packages

```
ros2/
├── wamoduck_msgs/          interface package (ament_cmake)
│   └── msg/JointTarget.msg       ROS-side image of the 46 B CMD frame payload
│   └── msg/LinkStatus.msg        link counters + cerebellum status word
├── wamoduck_description/   URDF + meshes + RViz (ament_cmake)
│   ├── scripts/generate_ros_urdf.py   rewrites mesh paths at build time
│   ├── urdf/README.md                 why no URDF is checked in here
│   ├── launch/display.launch.py       robot_state_publisher + joint_state_publisher + RViz
│   └── rviz/wamoduck.rviz, wamoduck_world.rviz
├── wamoduck_ros2/          nodes (ament_python)
│   ├── wamoduck_ros2/frame_codec.py       byte protocol, ROS-free, fully unit-tested
│   ├── wamoduck_ros2/model_contract.py    frozen policy contract + URDF joint reader
│   ├── wamoduck_ros2/gait_csv.py          reader for tools/matlab/data/gait_*.csv
│   ├── wamoduck_ros2/policy_interface.py  observation assembly, action permutation
│   ├── wamoduck_ros2/policy_runner.py     ONNX boundary (skeleton, never executed)
│   ├── wamoduck_ros2/gait_player.py       CSV -> sensor_msgs/JointState
│   ├── wamoduck_ros2/policy_node.py       50 Hz policy loop (skeleton)
│   ├── wamoduck_ros2/bridge_stub.py       byte transport <-> topics (skeleton + codec)
│   └── launch/gait_display.launch.py      gait_player + RViz, one command
├── tools/verify_description.py   independent geometric verification of the description
└── verification/                 evidence produced by the runs described below
```

The node split follows `docs/16_真机部署方案.md` §6.5: **ROS lives only on the Linux side**
(no micro-ROS on the AT32, whose 96+12 KB SRAM cannot comfortably hold a DDS session), the
wire protocol is the deterministic 46-byte frame format, and the bridge is the only
component that parses bytes. Plain `rclpy`, no real-time kernel. Name mapping:

| `docs/16` §6.5 | this package |
| --- | --- |
| `wmduck_bridge` | `bridge_stub` |
| `wmduck_policy` | `policy_node` |
| `wmduck_safety` | **not written** (a later stage) |
| `wmduck_msgs/JointTarget` | `wamoduck_msgs/JointTarget` |

### Assets are never stored twice

`models/wmduck/` stays the single source of truth. This directory contains **no meshes and no
URDF**, and `tools/matlab/data/` stays the single source of truth for the gait CSVs.

* `wamoduck_description` rewrites the canonical URDF's mesh references from the
  file-relative `meshes/Head.stl` to `package://wamoduck_description/meshes/Head.stl` at
  build time, and installs the meshes straight out of `models/wmduck/meshes`.
* `wamoduck_ros2` installs `tools/matlab/data/gait_*.csv` into `share/wamoduck_ros2/data`.

Both are build-time copies, so the ~11 MB of STL exists exactly once inside Git. See
[`wamoduck_description/urdf/README.md`](wamoduck_description/urdf/README.md) for why
symlinks were rejected.

The rewrite is not cosmetic. `robot_state_publisher` + RViz resolve meshes through
`resource_retriever`, which understands `package://`, `file://` and paths relative to the
**current working directory** — never a URDF-relative path. Launch RViz from anywhere else
and the robot silently renders empty. `tools/verify_description.py` measures exactly this: run
against the canonical URDF it reports all 79 references as working-directory dependent, and
against the generated URDF it reports zero.

---

## Install

ROS 2 **Jazzy** (Ubuntu 24.04's matching distribution). Do not use Humble: that is the 22.04
release.

### Option A — everything, including RViz (a workstation)

```bash
sudo apt update
sudo apt install ros-jazzy-desktop
```

`ros-jazzy-desktop` is the simple choice and is what the verification below used
(`0.11.0-1noble`, RViz 14.1.23). It is roughly 1–2 GB.

### Option B — minimal (the RDK X5, or a machine with no display)

```bash
sudo apt install ros-jazzy-ros-base \
                 ros-jazzy-robot-state-publisher \
                 ros-jazzy-joint-state-publisher
# only if you want RViz on that machine too:
sudo apt install ros-jazzy-rviz2
```

`ros-jazzy-ros-base` is enough for the nodes. `wamoduck_description` needs
`robot_state_publisher` only if something consumes its TF; RViz needs the `rviz2` package plus
the `rviz_default_plugins` that come with it.

### Build and test tooling

```bash
sudo apt install python3-colcon-common-extensions python3-pytest
# optional, used by the verification notes in this directory:
sudo apt install liburdfdom-tools ros-jazzy-tf2-tools
```

`liburdfdom-tools` provides the standalone `/usr/bin/check_urdf`. The `check_urdf` on your
`PATH` after sourcing ROS 2 is the one from `ros-jazzy-urdf`; both work.

---

## Build

The packages live in a plain `ros2/` directory, not in a workspace `src/`. Two ways to build:

### Symlink the packages into a workspace (recommended)

Keeps one source of truth and avoids building on `/mnt/e` or any other slow/shared filesystem:

```bash
mkdir -p ~/ws_wamoduck/src
cd ~/ws_wamoduck
for p in wamoduck_msgs wamoduck_description wamoduck_ros2; do
  ln -sfn /path/to/Wamoduck/ros2/$p src/$p
done

source /opt/ros/jazzy/setup.bash
colcon build
source install/setup.bash
```

`wamoduck_description/CMakeLists.txt` resolves symlinks before walking up to `models/wmduck`,
so this layout works with the same default it uses in-place.

### Build in place

```bash
cd /path/to/Wamoduck/ros2
source /opt/ros/jazzy/setup.bash
colcon build
source install/setup.bash
```

### If only `ros2/` was copied to this machine

`wamoduck_description` deliberately carries no URDF, so it needs the model directory. Either
copy `models/wmduck/` alongside, or point the build at it:

```bash
colcon build --packages-select wamoduck_description \
  --cmake-args -DWAMODUCK_MODELS_DIR=/opt/wamoduck/models/wmduck
```

The build fails loudly, with that instruction, if `wmduck.urdf` or the mesh directory is
missing — rather than installing a description that renders an empty robot.

### Expected build result

```
Starting >>> wamoduck_description
Starting >>> wamoduck_msgs
Starting >>> wamoduck_ros2
...
Summary: 3 packages finished [21.6s]
```

If `colcon list` shows `wamoduck_ros2 (python)` instead of `(ros.ament_python)`, **stop**:
that means `package.xml` is not being parsed as a ROS manifest and no ROS environment is
generated for the package, so `ros2 launch` will never find it. The usual cause is an
unescaped `<` in an XML text field. `wamoduck_ros2/test/test_package_manifests.py` exists to
catch that, because `colcon build` succeeds either way.

---

## Run

### 1. Just look at the robot

```bash
ros2 launch wamoduck_description display.launch.py
```

`robot_state_publisher` + `joint_state_publisher` + RViz. All movable joints sit at 0, which
is the CAD standing pose, because the contract's `default_joint_pos` is all zeros.

Useful arguments:

| Argument | Default | Effect |
| --- | --- | --- |
| `rviz` | `true` | set `false` for a headless bring-up |
| `use_gui` | `false` | drag joint sliders with `joint_state_publisher_gui` |
| `use_joint_state_publisher` | `true` | set `false` when something else owns `/joint_states` |
| `rviz_config` | `<share>/rviz/wamoduck.rviz` | Fixed Frame `base_link` |
| `urdf_file` | generated URDF | publish a different description |

### 2. Watch it walk the reference gait

```bash
ros2 launch wamoduck_ros2 gait_display.launch.py
```

That is the whole one-click path: `gait_player` reads
`share/wamoduck_ros2/data/gait_cycle_2s_50Hz.csv` and publishes it as `sensor_msgs/JointState`
while `robot_state_publisher` turns it into TF and RViz draws it. The base trajectory from the
CSV's `base_x` / `base_y` / `base_z` / `base_roll_rad` is broadcast as `world -> base_link`,
so `gait_display.launch.py` selects `wamoduck_world.rviz` (Fixed Frame `world`) for you.

| Argument | Default | Effect |
| --- | --- | --- |
| `csv_path` | installed `gait_cycle_2s_50Hz.csv` | any other track, e.g. `gait_walk_1m_10Hz.csv` |
| `loop` | `true` | repeat forever |
| `time_scale` | `1.0` | playback rate multiplier |
| `start_delay_s` | `1.0` | let RViz load meshes before the first sample |
| `publish_base_tf` | `true` | `false` also switches RViz to Fixed Frame `base_link` |
| `rviz` | `true` | `false` runs the player headless |

The two reference tracks are quasi-static **kinematic IK plans**, not hardware logs and not
the output of a trained policy: `step_len = 0.01 m`, `speed = 0.01 m/s` for both. The player's
own log line reports its achieved rate so the timing can be checked rather than trusted.

### 3. The nodes on their own

```bash
# gait replay without a display
ros2 run wamoduck_ros2 gait_player --ros-args -p csv_path:=/abs/path.csv

# the same, with the convenience flag; --loop is not a ROS argument, it is stripped
ros2 run wamoduck_ros2 gait_player --loop

# protocol bridge, loopback transport, no hardware required
ros2 run wamoduck_ros2 bridge_stub

# policy loop (skeleton: assembles observations, never infers)
ros2 run wamoduck_ros2 policy_node
```

### 4. Inspect what is flowing

```bash
ros2 topic echo /joint_states --once
ros2 topic hz /joint_states
ros2 topic echo /tf --once
ros2 run tf2_tools view_frames          # needs graphviz
```

---

## The 46-byte link, in one page

`wamoduck_ros2/frame_codec.py` implements deployment protocol v1. It is wire-compatible with
the reference implementation in the internal engineering tree, and it is deliberately ROS-free
so it can be tested without a graph or hardware.

```
SOF(0xA5) | TYPE | LEN | SEQ | PAYLOAD | CRC16(TYPE..PAYLOAD)
   1 B      1 B    1 B   1 B     LEN B          2 B
```

CRC is **CRC16-CCITT-FALSE** (poly `0x1021`, init `0xFFFF`, no reflection, no final xor);
`CRC16-CCITT-FALSE(b"123456789") == 0x29B1` is asserted by the test suite, because a wrong CRC
variant fails only on the wire and looks exactly like a noisy cable. All integers are
little-endian.

| Direction | TYPE | Name | Payload | Frame | Rate |
| --- | --- | --- | ---: | ---: | --- |
| host → cerebellum | `0x01` | `CMD` | 40 B: `mode, flags, t_ms, q[14] i16, twist[3] i16` | **46 B** | 50 Hz |
| host → cerebellum | `0x02` | `ESTOP` | empty | 6 B | event |
| cerebellum → host | `0x81` | `STATE_Q` | 32 B: `age_ms, q[14], status` | 38 B | 200 Hz |
| cerebellum → host | `0x82` | `STATE_DQ` | 32 B: `age_ms, dq[14], status` | 38 B | 200 Hz |
| cerebellum → host | `0x83` | `STATE_IMU` | 24 B: `age_ms, gyro[3], acc[3], quat[4] wxyz, status` | 30 B | 200 Hz (optional) |
| cerebellum → host | `0x84` | `EVENT` | 4 B: `code, arg` | 10 B | event |

Uplink is 106 B/round, i.e. 21.2 kB/s at 200 Hz, 23 % of a 921600 8N1 UART. Every payload is
≤ 64 B, so the same framing fits one CAN-FD message per frame with no change above the
transport.

Fixed-point scales: `q` rad→mrad ×1000, `dq` rad/s→0.01 ×100, `gyro` ×100, `acc` ×100,
`quat` ×30000, `twist` m/s→mm/s ×1000 and rad/s→mrad/s ×1000. Out-of-range values
**saturate**; they never wrap.

**Array order.** `q` and `dq` are always in *joint-tree order* — the 14-joint order in
`model_contract.JOINT_ORDER` — which is also the order of `joint_pos` / `joint_vel` inside the
policy observation, **and the order of the policy's own 14-wide output**. The permutation
between action and joint is therefore the identity, and it is still applied once, on the host,
in `policy_interface.action_to_joint_target()`.

Three different joint orders exist in this project and mixing them up is a known bug class.
The code keeps them apart, and `test_model_contract.py` asserts that the URDF's document order
**differs** from the contract order (so a future "tidy-up" fails the tests instead of silently
re-wiring a joint):

| Order | Where | Contents |
| --- | --- | --- |
| joint-tree order | `JOINT_ORDER`, 14 names | `left_hip_yaw, left_hip_roll, …, left_ankle, right_hip_yaw, …, head_roll` |
| actuator order | MJCF `<actuator>`, 14 | L/R interleaved per joint kind; **not** the action order — `action_to_joint` is the identity |
| URDF document order | `models/wmduck/wmduck.urdf`, 15 joints | L/R interleaved, plus `mouth` |

The action order was **adjudicated on 2026-09-16** in favour of joint-tree order. This module
previously read the action vector in actuator order; four independent lines of evidence settled
it: mjlab's own resolver on the training MJCF returns `target_ids = [0 … 13]`; every published
policy's ONNX metadata records `joint_names` in tree order; a one-hot MuJoCo probe driving one
action channel at a time moves `JOINT_ORDER[i]` and nothing else; and a 2×2 ablation over
observation × action order leaves only tree/tree standing, walking, crouching and getting up.
See the [`model_contract`](wamoduck_ros2/wamoduck_ros2/model_contract.py) module docstring.

`gait_player` reads the joint list **out of the URDF** and matches the CSV columns to it **by
name**; it hard-codes no order at all. It publishes all 15 movable joints, including `mouth`,
which the 14-joint policy contract does not use — that is the honest visualisation of the
description and does not change what the policies observe.

---

## The policy contract

`wamoduck_ros2/policy_node.py` is a **skeleton**: it assembles observations and publishes
nothing, because `onnxruntime` is not installed and no policy has been loaded on any machine
in this tree. What *is* implemented and unit-tested is the contract.

Observation, ONNX input order, **51** wide for the walk tasks:

```
offset  0  base_ang_vel        3   rad/s, IMU gyro, body frame
offset  3  projected_gravity   3   unit vector; upright is (0, 0, -1)
offset  6  joint_pos          14   rad, relative to default_joint_pos (which is all zeros)
offset 20  joint_vel          14   rad/s
offset 34  last_action        14   the previous raw policy output, before action_scale
offset 48  command             3   (vx, vy, wz), clamped to x[-0.6,1.0] y[-0.3,0.3] wz[-0.8,0.8]
------------------------------------------------------------------------------
total                         51
```

The **stand** policies were trained with **48** inputs: the same layout with the trailing
`command` block absent. 48 and 51 are not interchangeable.

* **The normalizer is inside the ONNX graph** (`normalizer_inside_onnx: true`), so the host
  feeds **raw** observations. Normalising again on the device applies the transform twice —
  the classic way to get a policy that trains well and stands badly.
* The action is 14 wide in **joint-tree order**, the same order as the observation;
  `action_to_joint` is applied once, on the host, and is the identity.
* `q_target[joint] = default_joint_pos[joint] + action_scale * action[joint]`, with
  `default_joint_pos` all zeros and `action_scale` 1.0, so in practice `q_target = action`.
* Timing: **50 Hz**, MuJoCo `timestep = 0.005 s`, `decimation = 4` ⇒ `0.005 × 4 = 0.02 s`.
* State topics use **BEST_EFFORT + KEEP_LAST(1)**. With RELIABLE and a deeper queue, one slow
  callback leaves stale observations queued and the policy reasons about tens-of-milliseconds-old
  state; the symptom is "sluggish and oscillating", and it is hard to find afterwards.
* Start-up order: bridge and safety first, policy last. A policy that is not ready leaves the
  cerebellum on its watchdog (HOLD at 200 ms, OFF at 1000 ms). That is the intended default.

---

## Verification status

Everything below was run inside **WSL2 Ubuntu 24.04 (x86_64)** with ROS 2 **Jazzy**.
Artifacts are in [`verification/`](verification/); see
[`verification/README.md`](verification/README.md) for the exact commands.

| # | Check | Result | Evidence |
| --- | --- | --- | --- |
| 1 | `colcon build` | **PASS** — 3 packages, 0 failures, `Summary: 3 packages finished [21.6s]` | `verification/colcon_build_log.txt` |
| 2 | `robot_state_publisher` + `gait_player`, `ros2 topic echo /joint_states --once` | **PASS** — 49.998–50.001 Hz, 15 named joints in URDF document order, non-zero and finite | `verification/runtime_verification_log.txt` |
| 3 | RViz renders the description | **PASS** — headless Xvfb + llvmpipe screenshot, and also under WSLg | `verification/rviz_gait_xvfb.png`, `verification/rviz_gait_wslg.png` |
| 4 | URDF parses and the geometry is right | **PASS** — `check_urdf` on both files, plus FK at q=0 vs the published `validation.json` (agreement to 3.1e-9 m) | `verification/description_check.json` |
| 5 | 46-byte frame codec round-trip, CRC vector, resync, saturation | **PASS** — 87 tests via `colcon test` and via direct `pytest` | `verification/static_verification_log.txt` |
| 6 | `policy_node` ONNX inference | **NOT RUN** — skeleton, `onnxruntime` not installed | `policy_runner.py` docstring |

The two screenshots show the same robot in different gait phases, taken about a minute apart
with `loop:=true` running, which is itself evidence that the track is being replayed.

### Explicitly not verified

* **ARM64 / RDK X5.** Every result here is from **x86_64 Ubuntu 24.04 in WSL2**. Nothing has
  been built or run on the X5's ARM64 userspace, and availability there is **unverified**.
  The packages are pure Python plus one `message` interface, so the port is expected to be
  uneventful, but "expected" is not "verified".
* **Hardware.** No serial port, no CAN bus, no AT32, no IMU, no motors. `bridge_stub`'s
  `serial` transport has never been opened, and its `can` transport is not written (it raises
  rather than starting a bridge that does nothing).
* **`policy_node` end to end.** No ONNX was loaded, no inference ran, no output was compared
  against a MuJoCo rollout.
* **`wmduck_safety`** (watchdog, e-stop aggregation, `/diagnostics`) is not written. The
  cerebellum-side protection layer (200 ms HOLD, 1000 ms OFF, 0.35 rad per frame, limit
  clamping) is specified in the protocol and lives in the firmware; the host deliberately does
  not duplicate it, because two watchdogs with different timeouts are worse than one.
* **Dynamics of any kind.** Stage 2 has no physics. The reference gait is a kinematic IK plan.
* **Gazebo and MoveIt.** Not started.
* **RViz on WSLg.** RViz starts under WSLg, but WSLg's window contents cannot be read back
  with `import`/`xwd`, so the screenshot evidence is the headless Xvfb render. See
  `verification/README.md`.

---

## Deploying to the RDK X5

Target: Ubuntu 22.04/24.04 ARM64 on the X5, with the robot's Linux side talking to the AT32
cerebellum over `/dev/ttyS1` or CAN-FD.

1. **Install ROS 2 on the X5.** Match the distro to the X5's Ubuntu release. The packages
   here are built and tested with Jazzy on 24.04.

   ```bash
   sudo apt install ros-jazzy-ros-base ros-jazzy-robot-state-publisher
   ```

   `ros-jazzy-rviz2` only if the X5 drives a display.

2. **Copy the sources and the model.** Either clone the repository, or copy `ros2/` plus
   `models/wmduck/`:

   ```bash
   rsync -a ros2/ x5:/opt/wamoduck/ros2/
   rsync -a models/wmduck/ x5:/opt/wamoduck/models/wmduck/
   rsync -a tools/matlab/data/ x5:/opt/wamoduck/tools/matlab/data/
   ```

   The third line matters: `wamoduck_ros2` installs the gait CSVs from there. Without it the
   package still builds (with a warning) and `gait_player` needs an explicit `csv_path`.

3. **Build on the X5.** Native ARM64 build; `colcon build` is enough, the packages are tiny.

   ```bash
   mkdir -p ~/ws/src && cd ~/ws
   ln -sfn /opt/wamoduck/ros2/wamoduck_msgs src/
   ln -sfn /opt/wamoduck/ros2/wamoduck_description src/
   ln -sfn /opt/wamoduck/ros2/wamoduck_ros2 src/
   source /opt/ros/jazzy/setup.bash
   colcon build --cmake-args -DWAMODUCK_MODELS_DIR=/opt/wamoduck/models/wmduck
   source install/setup.bash
   ```

   Omitting `-DWAMODUCK_MODELS_DIR` also works if the tree layout is preserved and the
   workspace `src/` entries are symlinks, because the description package resolves symlinks
   before walking up to `models/wmduck`.

4. **Start-up order** (`docs/16` §6.5 point 4): bridge and safety first, policy last.

   ```bash
   ros2 run wamoduck_ros2 bridge_stub --ros-args -p transport:=serial -p port:=/dev/ttyS1
   # ... then, once the state stream is healthy:
   ros2 run wamoduck_ros2 policy_node --ros-args -p onnx_path:=/opt/wamoduck/policies/....onnx
   ```

   For the 50 Hz joint loop, `docs/16` §6.5 recommends running policy and bridge in one process
   with intra-process communication (or in one node) to avoid the DDS round trip. The two are
   separate executables here, so this is an integration step still to be done.

5. **Before any of this drives a joint**, complete the calibration checklist in `docs/16` §5:
   zero offsets and sign per joint, measured limits, IMU axis mapping, and the five-parameter
   gain calibration. `policy_contract.json`'s `calibration` block is a placeholder with zeros,
   and `q = 0` is the CAD pose, **not** an encoder zero.

---

## Troubleshooting

| Symptom | Cause |
| --- | --- |
| `package 'wamoduck_ros2' not found` although `colcon build` succeeded | `package.xml` is not valid XML, so colcon classified it as plain `python`. Check `colcon list`: it must say `(ros.ament_python)`. |
| Robot renders empty in RViz | Mesh references are not `package://`. Run `tools/verify_description.py` — it checks this against an arbitrary working directory. |
| `colcon build` fails with "canonical URDF not found" | Only `ros2/` was copied. Pass `-DWAMODUCK_MODELS_DIR=...`. |
| `colcon build` fails with "'data_files' must be relative" | colcon asserts relative `data_files` sources; `setup.py` converts the gait CSV paths with `os.path.relpath` for this reason. |
| RViz shows a tiny speck | The `Views` block in the `.rviz` file sets the orbit distance to 0.85–1.0 m; the RViz default of 10 m is far too wide for a 0.39 m robot. |
| An `.rviz` edit seems to have no effect | The configs are copied into `share/` at install time, so a rebuild is needed. Use `colcon build --symlink-install` to avoid this. |
| `gait_player` warns a URDF joint has no column | The CSV and the URDF disagree; the warning names the joint. It is published at 0.0 rather than silently dropped. |

## License

MIT, copyright © 2026 Wamotech — the same as the rest of this repository. See [`../LICENSE`](../LICENSE).

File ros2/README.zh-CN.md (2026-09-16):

# Wamoduck 的 ROS 2（Jazzy）链路

给**不熟悉 MuJoCo 的人**准备的一条 ROS 2 链路：装什么、怎么编译、怎么一键跑起来看到机器人动
——完全不碰物理引擎。

**本目录只做前两段。**

| 阶段 | 内容 | 状态 |
| --- | --- | --- |
| **1. 描述包 + 节点** | `wamoduck_msgs`、`wamoduck_description`、`wamoduck_ros2` | 已完成：编译、节点、话题均已验证（见[验证状态](#验证状态)） |
| **2. RViz 可视化** | `display.launch.py`、`gait_display.launch.py`、两个 `.rviz` 配置 | 已完成：截图证据在 [`verification/`](verification/) |
| 3. Gazebo | `ros-jazzy-ros-gz`、物理、控制器 | **未开工 —— 这里没有任何东西在跑 Gazebo** |
| 4. MoveIt | 运动规划 | **未开工** |

本目录**不声称** Gazebo 或 MoveIt 能用，也**不声称**任何实机效果；`ros-jazzy-ros-gz` 刻意不在依赖里。

> **第 2 段没有物理。** RViz 不积分动力学、不做碰撞、不加重力。屏幕上"看着像在走"只能证明：
> 描述包能加载、关节坐标系的位置和 URDF 说的**一致**、`JointState` 流是合法的。
> 它证明不了动力学或平衡。本项目的物理基准仍然是 MuJoCo。

---

## 包结构

```
ros2/
├── wamoduck_msgs/          接口包（ament_cmake）
│   └── msg/JointTarget.msg       46 B CMD 帧负载的 ROS 侧映像
│   └── msg/LinkStatus.msg        链路计数 + 小脑状态字
├── wamoduck_description/   URDF + 网格 + RViz（ament_cmake）
│   ├── scripts/generate_ros_urdf.py   编译期改写网格路径
│   ├── urdf/README.md                 为什么这里不存 URDF
│   ├── launch/display.launch.py       robot_state_publisher + joint_state_publisher + RViz
│   └── rviz/wamoduck.rviz, wamoduck_world.rviz
├── wamoduck_ros2/          节点（ament_python）
│   ├── wamoduck_ros2/frame_codec.py       二进制协议，不含 ROS，单元测试齐全
│   ├── wamoduck_ros2/model_contract.py    冻结的策略契约 + 从 URDF 读关节
│   ├── wamoduck_ros2/gait_csv.py          tools/matlab/data/gait_*.csv 的解析
│   ├── wamoduck_ros2/policy_interface.py  观测拼装、动作置换
│   ├── wamoduck_ros2/policy_runner.py     ONNX 边界（骨架，从未执行）
│   ├── wamoduck_ros2/gait_player.py       CSV → sensor_msgs/JointState
│   ├── wamoduck_ros2/policy_node.py       50 Hz 策略环（骨架）
│   ├── wamoduck_ros2/bridge_stub.py       字节传输 ↔ 话题（骨架 + 编解码器）
│   └── launch/gait_display.launch.py      gait_player + RViz，一条命令
├── tools/verify_description.py   与 RViz 无关的描述包几何校验
└── verification/                 下面那些验证跑出来的证据
```

节点划分遵循 `docs/16_真机部署方案.md` §6.5：**ROS 只留在 Linux 侧**（AT32 的 96+12 KB SRAM
跑 DDS 会话很紧，不跑 micro-ROS），线上协议是确定性的 46 B 帧格式，**只有 bridge 一个组件解析字节**。
全部是普通 `rclpy`，不需要实时内核。命名对应关系：

| `docs/16` §6.5 | 本包 |
| --- | --- |
| `wmduck_bridge` | `bridge_stub` |
| `wmduck_policy` | `policy_node` |
| `wmduck_safety` | **未编写**（后续阶段） |
| `wmduck_msgs/JointTarget` | `wamoduck_msgs/JointTarget` |

### 素材绝不存两份

`models/wmduck/` 始终是唯一出处。本目录**不含任何网格和 URDF**；步态 CSV 的唯一出处仍是
`tools/matlab/data/`。

* `wamoduck_description` 在编译期把规范 URDF 里的 `meshes/Head.stl` 改写成
  `package://wamoduck_description/meshes/Head.stl`，并直接从 `models/wmduck/meshes` 安装网格；
* `wamoduck_ros2` 把 `tools/matlab/data/gait_*.csv` 安装到 `share/wamoduck_ros2/data`。

两者都是**安装期拷贝**，所以 11 MB 的 STL 在 Git 仓库里只存在一份。为什么不用符号链接，见
[`wamoduck_description/urdf/README.md`](wamoduck_description/urdf/README.md)。

这个改写不是装饰性的：`robot_state_publisher` + RViz 通过 `resource_retriever` 解析网格，它只认
`package://`、`file://` 和**相对当前工作目录**的路径，**不认相对 URDF 的路径**。换个目录启动 RViz
机器人就会静默地画不出来。`tools/verify_description.py` 专门量化了这件事：对规范 URDF 它报告
79 处引用全部依赖工作目录，对生成后的 URDF 报告 0 处。

---

## 安装

ROS 2 **Jazzy**（Ubuntu 24.04 的配套版本）。**不要用 Humble**，那是 22.04 的。

### 方案 A —— 全装，含 RViz（工作站）

```bash
sudo apt update
sudo apt install ros-jazzy-desktop
```

省事，本文验证用的就是这个（`0.11.0-1noble`，RViz 14.1.23），大约 1–2 GB。

### 方案 B —— 最小（RDK X5，或无显示的机器）

```bash
sudo apt install ros-jazzy-ros-base \
                 ros-jazzy-robot-state-publisher \
                 ros-jazzy-joint-state-publisher
# 只有那台机器还要开 RViz 时才需要：
sudo apt install ros-jazzy-rviz2
```

跑节点 `ros-jazzy-ros-base` 就够。有东西要消费 `wamoduck_description` 的 TF 时才需要
`robot_state_publisher`；RViz 需要 `rviz2` 包以及随它来的 `rviz_default_plugins`。

### 编译与测试工具

```bash
sudo apt install python3-colcon-common-extensions python3-pytest
# 可选，本目录的验证脚本会用到：
sudo apt install liburdfdom-tools ros-jazzy-tf2-tools
```

`liburdfdom-tools` 提供独立的 `/usr/bin/check_urdf`。source 完 ROS 2 后 `PATH` 里的 `check_urdf`
来自 `ros-jazzy-urdf`，两个都能用。

---

## 编译

包放在普通的 `ros2/` 目录里，不在工作空间的 `src/` 下。两种编法：

### 软链接进工作空间（推荐）

保持单一出处，也避免在 `/mnt/e` 这类慢/共享文件系统上编译：

```bash
mkdir -p ~/ws_wamoduck/src
cd ~/ws_wamoduck
for p in wamoduck_msgs wamoduck_description wamoduck_ros2; do
  ln -sfn /path/to/Wamoduck/ros2/$p src/$p
done

source /opt/ros/jazzy/setup.bash
colcon build
source install/setup.bash
```

`wamoduck_description/CMakeLists.txt` 会**先解符号链接**再往上找 `models/wmduck`，所以软链接布局和
就地编译用的是同一个默认值。

### 就地编译

```bash
cd /path/to/Wamoduck/ros2
source /opt/ros/jazzy/setup.bash
colcon build
source install/setup.bash
```

### 只把 `ros2/` 拷到这台机器的情况

`wamoduck_description` 刻意不自带 URDF，所以它需要模型目录。要么把 `models/wmduck/` 一起拷过来，要么
指给编译：

```bash
colcon build --packages-select wamoduck_description \
  --cmake-args -DWAMODUCK_MODELS_DIR=/opt/wamoduck/models/wmduck
```

`wmduck.urdf` 或网格目录缺失时，编译会带上这句提示**直接失败**，而不是装出一个"看着是空的机器人"的描述包。

### 编译成功的标志

```
Starting >>> wamoduck_description
Starting >>> wamoduck_msgs
Starting >>> wamoduck_ros2
...
Summary: 3 packages finished [21.6s]
```

**如果 `colcon list` 显示的是 `wamoduck_ros2 (python)` 而不是 `(ros.ament_python)`，请停下来查。**
那说明 `package.xml` 没有被当成 ROS 清单解析，colcon 不会为该前缀生成任何 ROS 环境，
`ros2 launch` 永远找不到这个包。最常见的原因就是 XML 文本里有个没转义的 `<`。
`wamoduck_ros2/test/test_package_manifests.py` 就是为了兜住这一类错误——因为**编译在这两种情况下都会成功**。

---

## 运行

### 1. 先看看机器人长什么样

```bash
ros2 launch wamoduck_description display.launch.py
```

`robot_state_publisher` + `joint_state_publisher` + RViz。所有可动关节都在 0 位，也就是 CAD 站姿
——因为契约里的 `default_joint_pos` 就是全 0。

常用参数：

| 参数 | 默认 | 作用 |
| --- | --- | --- |
| `rviz` | `true` | 设 `false` 就是纯无头启动 |
| `use_gui` | `false` | 用 `joint_state_publisher_gui` 拖关节滑块 |
| `use_joint_state_publisher` | `true` | 有别的节点占用 `/joint_states` 时设 `false` |
| `rviz_config` | `<share>/rviz/wamoduck.rviz` | Fixed Frame 是 `base_link` |
| `urdf_file` | 生成的 URDF | 换成别的描述 |

### 2. 看它按参考步态动

```bash
ros2 launch wamoduck_ros2 gait_display.launch.py
```

这一条命令就是全部：`gait_player` 读 `share/wamoduck_ros2/data/gait_cycle_2s_50Hz.csv` 并按文件
自己的采样率发 `sensor_msgs/JointState`，`robot_state_publisher` 把它变成 TF，RViz 画出来。CSV 里的
`base_x`/`base_y`/`base_z`/`base_roll_rad` 会作为 `world -> base_link` 广播出去，所以
`gait_display.launch.py` 会自动选 `wamoduck_world.rviz`（Fixed Frame 为 `world`）。

| 参数 | 默认 | 作用 |
| --- | --- | --- |
| `csv_path` | 已安装的 `gait_cycle_2s_50Hz.csv` | 换别的轨迹，例如 `gait_walk_1m_10Hz.csv` |
| `loop` | `true` | 循环播放 |
| `time_scale` | `1.0` | 播放速率倍数 |
| `start_delay_s` | `1.0` | 等 RViz 载完网格再出第一个采样 |
| `publish_base_tf` | `true` | 设 `false` 时 RViz 也会自动切回 Fixed Frame `base_link` |
| `rviz` | `true` | 设 `false` 只跑步态播放 |

两个参考轨迹都是**准静态运动学 IK 规划**，不是实机日志，也不是训练策略的输出：两者
`step_len = 0.01 m`、`speed = 0.01 m/s`。播放节点会自己打印实测频率，时序可以核对而不是靠相信。

### 3. 单独跑节点

```bash
# 无显示器的步态回放
ros2 run wamoduck_ros2 gait_player --ros-args -p csv_path:=/abs/path.csv

# 同样的事，方便写法；--loop 不是 ROS 参数，会被剥掉
ros2 run wamoduck_ros2 gait_player --loop

# 协议桥，loopback 传输，不需要任何硬件
ros2 run wamoduck_ros2 bridge_stub

# 策略环（骨架：只拼观测，不做推理）
ros2 run wamoduck_ros2 policy_node
```

### 4. 看看线上有什么

```bash
ros2 topic echo /joint_states --once
ros2 topic hz /joint_states
ros2 topic echo /tf --once
ros2 run tf2_tools view_frames          # 需要 graphviz
```

---

## 46 字节链路，一页说完

`wamoduck_ros2/frame_codec.py` 实现的是部署协议 v1，与内部工程树里的参考实现线级兼容；它刻意不含
ROS，所以不依赖 ROS 图或硬件就能测。

```
SOF(0xA5) | TYPE | LEN | SEQ | PAYLOAD | CRC16(TYPE..PAYLOAD)
   1 B      1 B    1 B   1 B     LEN B          2 B
```

CRC 是 **CRC16-CCITT-FALSE**（poly `0x1021`、init `0xFFFF`、不反转、不异或输出）；测试里钉死了
`CRC16-CCITT-FALSE(b"123456789") == 0x29B1`。因为 CRC 变体选错**只会在线上暴露**，而且看起来和
"线缆有噪声"一模一样。所有多字节整数都是小端。

| 方向 | TYPE | 名称 | 负载 | 帧长 | 频率 |
| --- | --- | --- | ---: | ---: | --- |
| 头 → 小脑 | `0x01` | `CMD` | 40 B：`mode, flags, t_ms, q[14] i16, twist[3] i16` | **46 B** | 50 Hz |
| 头 → 小脑 | `0x02` | `ESTOP` | 空 | 6 B | 事件 |
| 小脑 → 头 | `0x81` | `STATE_Q` | 32 B：`age_ms, q[14], status` | 38 B | 200 Hz |
| 小脑 → 头 | `0x82` | `STATE_DQ` | 32 B：`age_ms, dq[14], status` | 38 B | 200 Hz |
| 小脑 → 头 | `0x83` | `STATE_IMU` | 24 B：`age_ms, gyro[3], acc[3], quat[4] wxyz, status` | 30 B | 200 Hz（可选） |
| 小脑 → 头 | `0x84` | `EVENT` | 4 B：`code, arg` | 10 B | 事件 |

上行每轮 106 B，200 Hz 时 21.2 kB/s，是 921600 8N1 的 23%。每个负载都 ≤ 64 B，所以同一套帧格式
可以一帧一条直接改走 CAN-FD，传输层以上一行都不用改。

定点比例：`q` rad→mrad ×1000、`dq` rad/s→0.01 ×100、`gyro` ×100、`acc` ×100、`quat` ×30000、
`twist` m/s→mm/s ×1000 与 rad/s→mrad/s ×1000。超范围的值**饱和**，绝不回绕。

**数组顺序。** `q` 与 `dq` 永远是**关节树顺序**，也就是 `model_contract.JOINT_ORDER` 里的 14 关节顺序，
它同时是策略观测里 `joint_pos`/`joint_vel` 的顺序，**也是策略自己那 14 维输出的顺序**。因此
"动作 → 关节"的置换就是恒等置换，它仍然只在主机侧施加一次，位置是
`policy_interface.action_to_joint_target()`。

本项目里同时存在**三套关节顺序**，混淆它们是已知的坑。代码把它们分开，并且
`test_model_contract.py` 专门断言 URDF 的文档顺序**不同于**契约顺序——这样将来有人"整理"顺序时会
测试失败，而不是悄悄接错一根关节：

| 顺序 | 出处 | 内容 |
| --- | --- | --- |
| 关节树顺序 | `JOINT_ORDER`，14 个 | `left_hip_yaw, left_hip_roll, …, left_ankle, right_hip_yaw, …, head_roll` |
| 执行器顺序 | MJCF `<actuator>`，14 个 | 按关节种类左右交错；**不是**动作顺序——`action_to_joint` 是恒等置换 |
| URDF 文档顺序 | `models/wmduck/wmduck.urdf`，15 个 | 左右交错，且多一个 `mouth` |

动作顺序已于 **2026-09-16 裁决**为关节树顺序。本模块此前按执行器顺序解读动作向量；四条互相独立的
证据定了案：mjlab 自己的解析器在训练 MJCF 上返回 `target_ids = [0 … 13]`；每个已发布策略的 ONNX
元数据里 `joint_names` 都是树序；一次 one-hot 的 MuJoCo 探针逐个驱动动作通道时，动的正是
`JOINT_ORDER[i]` 且只有它；以及观测顺序 × 动作顺序的 2×2 消融里，只有树序／树序还能站、能走、
能蹲起、能起身。详见 [`model_contract`](wamoduck_ros2/wamoduck_ros2/model_contract.py) 的模块文档。

`gait_player` 的关节表是**从 URDF 里读的**，CSV 列是**按名字**匹配的，它自己一个顺序都不写死。它发布
全部 15 个可动关节（含 `mouth`，14 关节的策略契约不用它）——那是对描述包最诚实的可视化，不改变策略观测到什么。

---

## 策略契约

`wamoduck_ros2/policy_node.py` 是**骨架**：只拼观测，什么都不发，因为 `onnxruntime` 没装、这棵代码树里
任何机器都没加载过策略。真正实现并且有单元测试的是**契约**。

观测向量，按 ONNX 输入顺序，行走任务是 **51** 维：

```
offset  0  base_ang_vel        3   rad/s，IMU 陀螺，机体系
offset  3  projected_gravity   3   单位向量；直立时 = (0, 0, -1)
offset  6  joint_pos          14   rad，相对 default_joint_pos（而它全 0）
offset 20  joint_vel          14   rad/s
offset 34  last_action        14   上一帧策略原始输出，**未乘** action_scale
offset 48  command             3   (vx, vy, wz)，限幅到 x[-0.6,1.0] y[-0.3,0.3] wz[-0.8,0.8]
------------------------------------------------------------------------------
合计                          51
```

**站立**任务训练时是 **48** 维：同样的布局，去掉末尾的 `command` 块。48 和 51 不可互换。

* **归一化在 ONNX 图里面**（`normalizer_inside_onnx: true`），所以主机侧喂**原始**观测。设备侧再归一化
  一次等于把变换做了两遍——这是"训练挺好、站得挺差"最经典的成因。
* 动作是 14 维**关节树顺序**，与观测同一个顺序；`action_to_joint` 只在主机侧施加一次，且是恒等置换。
* `q_target[joint] = default_joint_pos[joint] + action_scale * action[joint]`，其中
  `default_joint_pos` 全 0、`action_scale` 为 1.0，所以实际就是 `q_target = action`。
* 时序：**50 Hz**，MuJoCo `timestep = 0.005 s`，`decimation = 4` ⇒ `0.005 × 4 = 0.02 s`。
* 状态类话题用 **BEST_EFFORT + KEEP_LAST(1)**。如果是 RELIABLE 且队列更深，某次回调慢一下就会在队列里
  积压旧状态，策略拿着滞后几十毫秒的观测推理；症状是"迟钝、振荡"，事后极难查。
* 启动顺序：bridge 与 safety 先起，policy 最后起。policy 没就绪时小脑靠看门狗停在 HOLD/OFF
  （200 ms → HOLD，1000 ms → OFF），**这是刻意的默认值**。

---

## 验证状态

以下全部跑在 **WSL2 Ubuntu 24.04（x86_64）** + ROS 2 **Jazzy**。证据文件在
[`verification/`](verification/)，具体命令见 [`verification/README.md`](verification/README.md)。

| # | 检查项 | 结果 | 证据 |
| --- | --- | --- | --- |
| 1 | `colcon build` | **通过** —— 3 个包，0 失败，`Summary: 3 packages finished [21.6s]` | `verification/colcon_build_log.txt` |
| 2 | `robot_state_publisher` + `gait_player`，`ros2 topic echo /joint_states --once` | **通过** —— 49.998–50.001 Hz，15 个关节名且顺序等于 URDF 文档顺序，数值非零且有限 | `verification/runtime_verification_log.txt` |
| 3 | RViz 渲染描述包 | **通过** —— 无头 Xvfb + llvmpipe 截图，WSLg 下也拿到了截图 | `verification/rviz_gait_xvfb.png`、`verification/rviz_gait_wslg.png` |
| 4 | URDF 能解析，且几何位置正确 | **通过** —— 两个 URDF 都过 `check_urdf`，并在 q=0 做正运动学与已发布的 `validation.json` 对比（吻合到 3.1e-9 m） | `verification/description_check.json` |
| 5 | 46 B 帧编解码往返、CRC 已知向量、重同步、饱和 | **通过** —— `colcon test` 与直接 `pytest` 共 87 个测试全过 | `verification/static_verification_log.txt` |
| 6 | `policy_node` 的 ONNX 推理 | **未运行** —— 骨架，未装 `onnxruntime` | `policy_runner.py` 文档字符串 |

两张截图是同一台机器人在**不同步态相位**下的画面，中间隔了约一分钟、`loop:=true` 一直在跑，
这本身就是"轨迹在循环回放"的证据。

### 明确未验证的事

* **ARM64 / RDK X5。** 这里所有结果都来自 **WSL2 里的 x86_64 Ubuntu 24.04**。X5 的 ARM64 用户态上
  **没有编译过、也没有运行过**，**可用性属于未验证**。包本身是纯 Python 加一个消息接口，移植预计不会
  有波折，但"预计"不是"已验证"。
* **硬件。** 没有串口、没有 CAN、没有 AT32、没有 IMU、没有电机。`bridge_stub` 的 `serial` 传输从未
  打开过，`can` 传输根本没写（它会直接报错，而不是起一个什么都不做的桥）。
* **`policy_node` 端到端。** 没加载过 ONNX、没跑过推理、没和 MuJoCo rollout 比对过输出。
* **`wmduck_safety`**（看门狗、急停汇聚、`/diagnostics`）未编写。小脑侧保护层（200 ms HOLD、
  1000 ms OFF、单帧 0.35 rad、限位夹取）写在协议规范里、实现在固件侧；主机侧**刻意不重复实现**
  ——两个超时不同的看门狗比一个好不了，只会更糟。
* **任何动力学。** 第 2 段没有物理。参考步态是运动学 IK 规划。
* **Gazebo 与 MoveIt。** 未开工。
* **WSLg 下的 RViz。** RViz 在 WSLg 下能起来，但 WSLg 的窗口内容无法用 `import`/`xwd` 回读（根窗口）；
  本次改为按窗口 id 截取客户端窗口并成功拿到 1400×900 的渲染图。截图证据见 `verification/README.md`。

---

## 部署到 RDK X5

目标：X5 上的 Ubuntu 22.04/24.04 ARM64，Linux 侧通过 `/dev/ttyS1` 或 CAN-FD 与 AT32 小脑通信。

1. **在 X5 上装 ROS 2。** 发行版要和 X5 的 Ubuntu 版本对上。本目录是用 24.04 + Jazzy 编译验证的。

   ```bash
   sudo apt install ros-jazzy-ros-base ros-jazzy-robot-state-publisher
   ```

   只有 X5 要接显示器时才需要 `ros-jazzy-rviz2`。

2. **拷源码和模型。** 要么整库 clone，要么把 `ros2/` 连同 `models/wmduck/` 一起拷：

   ```bash
   rsync -a ros2/ x5:/opt/wamoduck/ros2/
   rsync -a models/wmduck/ x5:/opt/wamoduck/models/wmduck/
   rsync -a tools/matlab/data/ x5:/opt/wamoduck/tools/matlab/data/
   ```

   第三行不能省：`wamoduck_ros2` 是从那里安装步态 CSV 的。省了也不会编译失败（只会警告），
   但 `gait_player` 就必须显式给 `csv_path`。

3. **在 X5 上本机编译。** 原生 ARM64 编译，`colcon build` 够了，包很小。

   ```bash
   mkdir -p ~/ws/src && cd ~/ws
   ln -sfn /opt/wamoduck/ros2/wamoduck_msgs src/
   ln -sfn /opt/wamoduck/ros2/wamoduck_description src/
   ln -sfn /opt/wamoduck/ros2/wamoduck_ros2 src/
   source /opt/ros/jazzy/setup.bash
   colcon build --cmake-args -DWAMODUCK_MODELS_DIR=/opt/wamoduck/models/wmduck
   source install/setup.bash
   ```

   目录结构保持一致、且 `src/` 下是软链接时，不加 `-DWAMODUCK_MODELS_DIR` 也行——描述包会先解符号
   链接再往上找 `models/wmduck`。

4. **启动顺序**（`docs/16` §6.5 第 4 点）：bridge 与 safety 先起，policy 最后起。

   ```bash
   ros2 run wamoduck_ros2 bridge_stub --ros-args -p transport:=serial -p port:=/dev/ttyS1
   # …… 等状态流健康之后：
   ros2 run wamoduck_ros2 policy_node --ros-args -p onnx_path:=/opt/wamoduck/policies/....onnx
   ```

   50 Hz 关节环上，`docs/16` §6.5 建议 policy 与 bridge 走同一进程 + 进程内通信（或者干脆写在一个
   节点里），省掉 DDS 往返。这里两者是两个可执行文件，所以这一步集成**还没做**。

5. **在让它驱动任何关节之前**，先把 `docs/16` §5 的标定清单做完：逐关节零偏与方向、实测限位、IMU 轴系
   映射、五参数增益标定。`policy_contract.json` 里的 `calibration` 块是占位全 0，并且
   `q = 0` 是 CAD 姿态，**不是**编码器零位。

---

## 排错

| 现象 | 原因 |
| --- | --- |
| `colcon build` 成功，但 `package 'wamoduck_ros2' not found` | `package.xml` 不是合法 XML，colcon 把它归类成了普通 `python`。看 `colcon list`，必须是 `(ros.ament_python)`。 |
| RViz 里机器人是空的 | 网格引用不是 `package://`。跑 `tools/verify_description.py`，它会用任意工作目录去检验这件事。 |
| 编译报 "canonical URDF not found" | 只拷了 `ros2/`。加 `-DWAMODUCK_MODELS_DIR=...`。 |
| 编译报 "'data_files' must be relative" | colcon 断言 `data_files` 的源必须是相对路径；`setup.py` 因此用 `os.path.relpath` 转换步态 CSV 路径。 |
| RViz 里机器人只有一个小点 | `.rviz` 里的 `Views` 块把轨道距离设成了 0.85–1.0 m；RViz 默认的 10 m 对 0.39 m 的机器人太远。 |
| 改了 `.rviz` 好像没生效 | 配置是安装期拷到 `share/` 的，必须重编译。用 `colcon build --symlink-install` 可以免掉这一步。 |
| `gait_player` 警告某个 URDF 关节没有对应列 | CSV 与 URDF 不一致，警告里点名了关节。它按 0.0 发布，而不是悄悄丢掉。 |

## 许可

MIT，版权 © 2026 Wamotech —— 与仓库其余部分一致。见 [`../LICENSE`](../LICENSE)。

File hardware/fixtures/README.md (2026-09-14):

# Calibration fixtures / 标定工装

| Fixture / 工装 | Files and instructions / 文件与说明 |
| --- | --- |
| Assembled-robot standing zero fixture / 整机站姿零位工装 | [English](standing-zero/README.md) · [中文](standing-zero/README.zh-CN.md) · [H2D PLA project](standing-zero/bambu/H2D_PLA_standing_zero.3mf) |

The standing fixture has four printable parts, one of each, joined with six M3 screws. STEP geometry, millimeter STL files, the maintainer's two-plate H2D project, and assembly instructions are supplied together. / 站姿工装共四个打印件，每件一份，以六颗 M3 螺钉连接；配套提供 STEP、毫米单位 STL、维护者保存的 H2D 双盘工程和装配说明。

For robot structural parts, start with the [mechanical guide](../../docs/mechanical.en.md) / [机械指南](../../docs/mechanical.zh-CN.md).

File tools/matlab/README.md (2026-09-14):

# MATLAB reference-gait player / MATLAB 参考步态回放器

[English home](../../README.md) · [中文首页](../../README.zh-CN.md) · [Gait guide (EN)](../../docs/matlab.en.md) · [步态指南（中文）](../../docs/matlab.zh-CN.md)

| File / 文件 | Purpose / 用途 |
| --- | --- |
| [wamoduck_play.m](wamoduck_play.m) | Interactive player for the reference gait: play/pause, step size, two data sets, skeleton or mesh view, per-joint angle/torque table / 参考步态交互回放器：播放暂停、推进步长、两份数据、骨架或网格显示、逐关节角度与力矩表 |
| [data/gait_cycle_2s_50Hz.csv](data/gait_cycle_2s_50Hz.csv) | One full gait cycle, 100 frames at 50 Hz (2.0 s, 2 cm forward) / 一个完整步态周期，50 Hz 共 100 帧（2.0 s，前进 2 cm） |
| [data/gait_walk_1m_10Hz.csv](data/gait_walk_1m_10Hz.csv) | The full 1 m walk, decimated to 10 Hz (104 s; 10 cm/s of playback is not implied) / 整段 1 m 行走，抽稀到 10 Hz（104 s） |

```matlab
% MATLAB R2021b+ with Robotics System Toolbox / 需要 R2021b+ 与 Robotics System Toolbox
cd <repo>            % the folder that contains models/ and tools/ / 含 models 与 tools 的那层
addpath('tools/matlab')
wamoduck_play        % interactive / 交互
wamoduck_play(true)  % full-row headless self-test / 全行无界面自检
```

## Data format / 数据格式

One CSV per data set, with a single `#` provenance line first (**`readtable` needs `'CommentStyle','#'`** / 首行是 `#` 开头的说明，**`readtable` 必须加 `'CommentStyle','#'`**):

| Column / 列 | Unit / 单位 | Meaning / 含义 |
| --- | --- | --- |
| `t_s` | s | Sample time, 50 Hz or 10 Hz / 采样时刻 |
| `q_<joint>` × 15 | **rad** | Joint angle for all 15 revolute joints, including `mouth` / 15 个转动关节角（含 `mouth`） |
| `tau_<joint>` × 15 | **N·m** | Inverse-dynamics torque estimate / 逆动力学力矩估计 |
| `base_x`, `base_y`, `base_z` | m | Body (`base_link`) position / 机体位置 |
| `base_roll_rad` | rad | Body roll about X; pitch and yaw are zero in this plan / 机体绕 X 侧倾，本规划中俯仰与偏航为 0 |

Angles are given in **radians** so that they can be passed straight into `show()`/`homeConfiguration` with **no unit conversion anywhere**. / 角度用**弧度**给出，可直接送进 `show()`／`homeConfiguration`，**全程不做单位换算**。

The cycle file starts at a **steady-state** cycle (a transient first cycle was excluded) and its loop seam is one frame step (0.13°), so it can be played as a seamless loop. / 周期文件取的是**稳态**周期（已排除起步那一圈），循环接缝等于一帧步进（0.13°），可无缝循环。

## Scope / 口径

This is a **kinematic replay**: prescribed joint angles plus forward kinematics. There is no physics integration, no controller, no ONNX policy, and no hardware data. The unpublished trajectory generator produced the plan in a separate project; this player only replays the CSV and does not recompute IK or inverse dynamics. The torques are model-based estimates, not measurements. The bundled 10 Hz walk CSV has an actual peak of **2.50815 N·m**; the separately reported full-rate planning peak is 2.53 N·m. / 这是**运动学回放**：给定关节角 + 前向运动学，不含物理积分、不含控制器、不是 ONNX 策略、不是实物数据。未公开的轨迹生成器在独立项目中生成规划；本回放器只读取 CSV，不重算 IK 或逆动力学。力矩是模型估计值，不是实测。随附 10 Hz 全程 CSV 的实际峰值为 **2.50815 N·m**；另行报告的全采样率规划峰值为 2.53 N·m。

`wamoduck_play(true)` retains the existing quick smoke test: it samples the middle row of each CSV, checks joint limits and a coarse ±20 mm sole-height range, then saves a hidden-figure screenshot. It is not an all-frame contact or balance test. / `wamoduck_play(true)` 保留原有快速自检：抽查两份 CSV 各自的中间帧，检查关节限位与粗略的 ±20 mm 脚底高度范围，并保存隐藏图形截图；它不代表全帧接触检查或平衡验证。

The URDF `q=0` pose is not an actuator encoder zero. The [standing-zero fixture](../../hardware/fixtures/standing-zero/README.md) / [站姿零位工装](../../hardware/fixtures/standing-zero/README.zh-CN.md) can help measure encoder offsets, but this player neither applies those offsets nor sends commands to hardware. / URDF 的 `q=0` 姿态不是执行器编码器零位；工装可辅助测量偏置，本回放器既不应用偏置，也不向实机发送指令。

## Known limitations / 已知限制

- **MATLAB figure rendering is the bottleneck, not the data.** A bare `drawnow` on this machine costs ~0.17 s, so the mesh view runs at well under 1 fps and the skeleton view at a few fps. The default **skeleton view** exists for that reason; use it to watch motion and switch to the mesh view to inspect a pose. / **瓶颈是 MATLAB 的图形刷新，不是数据**：本机一次空 `drawnow` 约 0.17 s，所以网格视图不到 1 fps、骨架视图几 fps。默认用**骨架视图**看运动，切到网格视图看姿态。
- The locomotion is a **low-clearance quasi-static shuffle**, with one foot lifting about 4.5 mm while the other stays in contact; it is not a dynamic walk. See the [gait guide](../../docs/matlab.en.md#what-the-gait-does-and-does-not-do) for the model calculations. / 这是**低抬脚的准静态蹭步**：一只脚抬高约 4.5 mm 时另一只脚保持接地；它不是动态行走。模型计算口径见[步态指南](../../docs/matlab.zh-CN.md)。
- `wamoduck_play` is a **viewer**. It contains no balance controller and does not attempt to keep the robot upright. / `wamoduck_play` 只是**查看器**，不含平衡控制器。

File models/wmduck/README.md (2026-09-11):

# Wamoduck robot description / 机器人描述

[English model guide](../../docs/model.en.md) · [中文模型指南](../../docs/model.zh-CN.md)

Open [`wmduck.urdf`](wmduck.urdf) with its [`meshes/`](meshes/) folder present. This package has 15 revolute joints, 1 fixed joint, and 20 meter-scale STL files. / 打开 [`wmduck.urdf`](wmduck.urdf) 时请保留配套 [`meshes/`](meshes/) 文件夹；本包包含 15 个转动关节、1 个固定关节和 20 个米制 STL。

| File / 文件 | Purpose / 用途 |
| --- | --- |
| [wmduck.urdf](wmduck.urdf) | Main model / 主模型 |
| [joint_parameters.json](joint_parameters.json) | Joint assumptions; editing this file alone does not update the URDF / 关节参数记录，单独修改不会更新 URDF |
| [joint_limits.csv](joint_limits.csv) | Geometric range estimates and their basis / 几何限位估计与依据 |
| [motor_parameters.json](motor_parameters.json) | Transcribed motor assumptions / 电机参数记录 |
| [component_mass_audit.csv](component_mass_audit.csv) | Modeled instance masses and sources / 模型实例质量与来源 |
| [validation.json](validation.json) | Current package structural and import checks / 当前资料包结构与导入检查 |

This is a model for inspection and development. It does not include a controller, actuators, a ground scene, or training code. / 这是用于查看与开发的模型，不含控制器、执行器定义、地面场景或训练代码。

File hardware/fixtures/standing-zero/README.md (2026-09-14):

# Standing zero fixture

English | [简体中文](README.zh-CN.md)

A four-part PLA fixture for placing an assembled Wamoduck in its saved standing pose and recording the output-side encoder offsets of its 15 servos. The fixture locates the feet, the confirmed lower hip-motor housing faces, Body, head, and closed mouth. Screws join the fixture parts; no screws attach it to the robot.

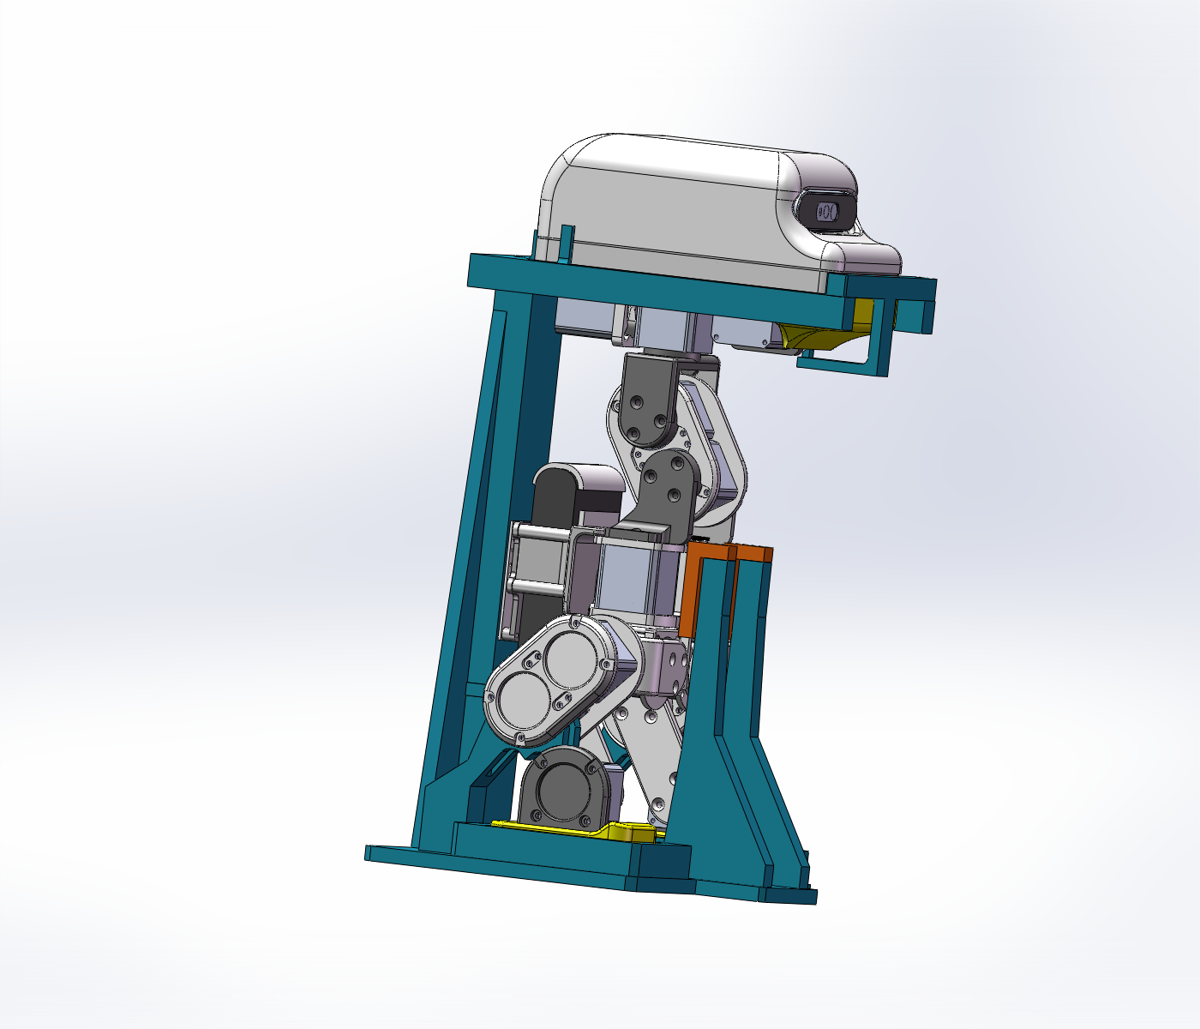
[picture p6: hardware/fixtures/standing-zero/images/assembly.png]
Current fixture and robot in the reference pose


This package includes the maintainer's **2026-09-14 P01 revision** and their matching H2D project. The source SolidWorks parts were opened read-only for the new STEP exports and CAD checks.

## Download and print

1. Download the repository, then open [H2D_PLA_standing_zero.3mf](bambu/H2D_PLA_standing_zero.3mf) **as a project** in Bambu Studio. It contains both plates, all four parts, orientations, and saved settings. Bambu Studio 02.08.02.60 authored this project.
2. Confirm H2D, 0.4 mm nozzle, PLA, and the installed plate. The saved plate is SuperTack and all parts use filament slot 1, Bambu PLA Basic. Select your actual consumable/plate profile if different.
3. Slice both plates and inspect support contact and the tall mast before printing. This 3MF contains no G-code; it must be sliced. Print plate 1 once and plate 2 once. Do not add a second copy of the separately supplied STL files to the project.

| Part | Quantity | H2D plate | Print envelope, mm | Function |
| --- | ---: | ---: | --- | --- |
| [P01_Main_frame](stl/P01_Main_frame.stl) | 1 | 1 | 200 × 260 × 315.83 | Base, foot pockets, V saddles, front braces, rear mast and ribs |
| [P02_Head_cradle](stl/P02_Head_cradle.stl) | 1 | 2 | 220.5 × 130.4 × 38.8 | Head cradle and rear/side stops |
| [P03_Head_keeper_mouth](stl/P03_Head_keeper_mouth.stl) | 1 | 2 | 130.4 × 54.112 × 47 | Front head keeper and mouth support |
| [P04_Body_bridge](stl/P04_Body_bridge.stl) | 1 | 2 | 28.249 × 52 × 64 | Body front restraint with integral contact faces |

**Total: four printed pieces and six screws.** The machine-readable list is [print-parts.csv](print-parts.csv).

The saved process uses 0.20 mm layers, **2 walls, 20% honeycomb infill, automatic 5 mm brim, normal automatic support, and no raft**, printing by layer. These are the maintainer's project settings, preserved as supplied; earlier local recommendations of 6 walls and 35–45% infill are not the settings in this download. No physical print or load-test results are included yet.

For manual slicing, the STL files already have their intended print orientations: P01 upright on its base, P02 bottom down, P03 on its outer flat face, and P04 on its side. P01 fits the checked H2D envelope of 325 × 320 × 325 mm, with about 9.17 mm of height remaining before slicer additions. Verify the complete sliced envelope, including adhesion/support structures. Keep support interfaces off the locating surfaces where practical, and remove support residue before fitting.

## Files, units, and revisions

| Folder/file | Purpose |
| --- | --- |
| [step/](step/) | Four neutral CAD solids for geometry editing, in millimeters and the common assembly coordinate system |
| [stl/](stl/) | Four printable meshes in millimeters, oriented for printing |
| [bambu/](bambu/) | Two-plate H2D PLA project with embedded meshes and settings |
| [validation.json](validation.json) | Version-specific digital geometry and package checks |
| [manifest.json](manifest.json) | File sizes, SHA-256 checksums, and export provenance |

STEP and STL provide geometry; a slicer turns either supported format into printer paths. The 3MF project additionally stores placement and printing settings. Bambu Studio's STEP/STL/3MF import is described in the [H2D user manual](https://csm.bblcdn.com/hub/4668d0ca43994ff3bff4b37f1a65c2e7.pdf).

STEP positions reproduce the fixture assembly; STL positions reproduce printing orientations. Their origins therefore differ. P01's public STL is only translated to a zero-based print bounding box; its shape and topology are unchanged from the maintainer's updated STL. P02–P04 are copied unchanged. The public 3MF removes an account identifier from metadata; meshes, layout, and process settings are unchanged. Native working files and obsolete local check reports are kept outside this public package.

## Fits and screws

Nominal dimensions: **M3×0.5 tap pilot Ø2.5 mm; clearance Ø3.3 mm; cup-head counterbore Ø6.5 × 3.2 mm deep; total mating clearance 0.4 mm**. The total clearance is not 0.4 mm on each side. It accommodates the specified PLA printing tolerance of ±0.2 mm as a design allowance; first-print fit still needs checking.

| Connection | Screws |
| --- | --- |
| P01 to P02 | 2 × M3×25 socket-head screws |
| P02 to P03 | 2 × M3×16 socket-head screws |
| P01 to P04 | 2 × M3×16 socket-head screws |

Deburr and remove elephant foot, then hand-tap the Ø2.5 holes M3×0.5. Check screw seating and blind-hole depth before installing the robot. Tighten each pair evenly by hand. No threaded inserts are required. Cup heads bear on the flat counterbore shoulder; do not apply C2 to the narrow bearing ring between Ø6.5 and Ø3.3. The mouth entry has its own C2 lead-in.

P02 rear-stop and outer side-post roots have R3 fillets. P03 has R4 at the mouth-arm inner root and R3 at the upper hanger root. These features are included in STEP, STL, and the 3MF.

[View the head-stop and mouth-support root details](images/roots.png).

## Assembly and calibration

The robot must be articulated into the integral saddles; the rigid standing assembly cannot simply be lowered vertically into the completed fixture.

1. Disable motor drive and confirm that the joints can be moved slowly by hand. Encoder/controller power may remain on for reading. Place P01 on a flat, stable surface.
2. Move the legs by hand and seat both feet in their pockets. Then move the relevant joints until the lower motor housing faces settle onto the two V saddles. Keep the wire exits clear.
3. Fit P02 to the mast key with two M3×25 screws and place the head lightly against its supports.
4. Slide P03 horizontally in from the robot front through its open locating channels, then secure it with two M3×16 screws. The mouth support is 0.2 mm below the modeled closed mouth: use the mechanism's closed state to establish mouth zero, rather than forcing it onto this face.
5. Fit P04 and slide the whole bridge along its fore/aft slots until its integral faces lightly touch Body. Secure it with two M3×16 screws. The bridge works with the lower/rear supports to restrain Body pitching forward; it has no independently adjustable contact pads.
6. With each required datum lightly seated and the drive disabled, record the corresponding output encoder readings/offsets. Avoid distorting the printed frame or pulling a joint into position with screws. Repeat placement to assess consistency before accepting calibration.

The encoders are internal to the motors and remain untouched. Record the robot's actual motor-ID mapping and sign convention separately. URDF `q=0` denotes the saved model pose, not a motor's factory encoder zero: the recorded offsets relate real encoder readings to that reference. The [MATLAB player](../../../tools/matlab/README.md) replays model joint coordinates and does not write calibration to hardware.

## Checked scope

The updated native CAD has one solid per part, no reported feature errors, and zero detected static overlaps involving the fixture at the saved robot pose. All four final STL meshes passed the recorded watertightness, degeneracy, and print-envelope checks. All four 3MF meshes match the corresponding source STL within numerical precision.

These checks cover the supplied digital files. First-print fit, structural loading, repeated placement accuracy, and a complete hardware calibration have not been measured in this package. This is a positioning fixture for manual calibration, not a powered motion-test stand.

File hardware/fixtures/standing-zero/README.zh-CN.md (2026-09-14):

# 整机站姿零位工装

[English](README.md) | 简体中文

用四个 PLA 打印件将已装配的 Wamoduck 定位到保存的默认站姿，再记录 15 个伺服电机的输出端编码器零偏。工装定位双脚、已确认的髋部下方电机壳体托面、Body、头部和闭合嘴部。螺钉只连接工装分件，工装与机器人之间不用螺钉固定。

当前工装与默认站姿模型

本目录采用维护者 **2026-09-14 手动优化的 P01**，以及与之匹配的 H2D 工程。重新导出 STEP、复核 CAD 时，原生 SolidWorks 文件均以只读方式打开。

## 下载与打印

1. 下载仓库，用 Bambu Studio **作为工程打开** [H2D_PLA_standing_zero.3mf](bambu/H2D_PLA_standing_zero.3mf)。工程包含两个打印盘、四个零件、摆放方向与参数，保存版本为 Bambu Studio 02.08.02.60。
2. 确认 H2D、0.4 mm 喷嘴、PLA 与实际使用的打印板。工程保存的是 SuperTack 板，全部零件使用耗材槽 1 的 Bambu PLA Basic；实际耗材或板型不同时，选择对应预设。
3. 重新切片两个盘，检查支撑接触与高立柱区域，再打印。该 3MF 不含 G-code，需要切片。第 1 盘和第 2 盘各打印一次即可，不要再向工程重复添加另附的 STL。

| 零件 | 打印数量 | H2D 打印盘 | 打印包络，mm | 功能 |
| --- | ---: | ---: | --- | --- |
| [P01_Main_frame](stl/P01_Main_frame.stl) | 1 | 1 | 200 × 260 × 315.83 | 底板、脚槽、V 托、前支撑、后立柱和加强筋一体 |
| [P02_Head_cradle](stl/P02_Head_cradle.stl) | 1 | 2 | 220.5 × 130.4 × 38.8 | 头部承托、后挡和侧挡 |
| [P03_Head_keeper_mouth](stl/P03_Head_keeper_mouth.stl) | 1 | 2 | 130.4 × 54.112 × 47 | 头部前挡与嘴部承托一体 |
| [P04_Body_bridge](stl/P04_Body_bridge.stl) | 1 | 2 | 28.249 × 52 × 64 | 带一体接触面的 Body 前桥 |

**合计四个打印件、六颗螺钉。** 数量表另存于 [print-parts.csv](print-parts.csv)。

工程实际保存的参数为：0.20 mm 层高、**2 道墙、20% 蜂窝填充、自动 5 mm brim、普通自动支撑、无 raft**，按层打印。这里原样保留维护者的工程设置；之前本地说明中的 6 道墙、35%～45% 填充不是本工程的参数。目前尚未附首件实打或承载测试记录。

自行切片时，STL 已按打印方向导出：P01 底板朝下立打、P02 底面朝下、P03 外侧平面朝下、P04 侧面朝下。按 325 × 320 × 325 mm 的 H2D 包络检查，P01 高度余量约 9.17 mm；应以切片后的模型、支撑和附着结构总体包络再次核对。尽量避开定位面设置支撑接触，试装前清除残留。

## 文件、单位与版本

| 目录／文件 | 用途 |
| --- | --- |
| [step/](step/) | 四个用于跨 CAD 软件编辑的实体，毫米单位，保留共同装配坐标 |
| [stl/](stl/) | 四个用于切片打印的网格，毫米单位，已设置打印朝向 |
| [bambu/](bambu/) | 内含模型、摆盘和打印设置的 H2D PLA 双盘工程 |
| [validation.json](validation.json) | 对应本版文件的数字几何与工程检查记录 |
| [manifest.json](manifest.json) | 文件大小、SHA-256 与导出来源记录 |

STEP 和 STL 都可将几何交给支持相应格式的切片软件；3MF 工程还保存摆放与打印设置。Bambu Studio 对 STEP／STL／3MF 的导入方法见 [H2D 用户手册](https://csm.bblcdn.com/hub/4668d0ca43994ff3bff4b37f1a65c2e7.pdf)。

STEP 保留装配位置，STL 保留打印朝向，因此两者原点不同。公开 P01 STL 仅平移到从零开始的打印包络，形状与拓扑不变；P02～P04 原样复制。公开 3MF 仅清除了一个账户标识，模型、摆盘和工艺参数不变。原生工作文件及旧校验报告保留在本地，不混入此公开目录。

## 配合与紧固件

设计名义值：**M3×0.5 攻牙底孔 Ø2.5 mm，过孔 Ø3.3 mm，杯头沉孔 Ø6.5 × 3.2 mm 深，分件总配合间隙 0.4 mm**。总间隙不是每侧 0.4 mm；它按 PLA 标称 ±0.2 mm 打印公差预留，实际首件配合仍需检查。

| 连接 | 螺钉 |
| --- | --- |
| P01 → P02 | 2 颗 M3×25 内六角杯头螺钉 |
| P02 → P03 | 2 颗 M3×16 内六角杯头螺钉 |
| P01 → P04 | 2 颗 M3×16 内六角杯头螺钉 |

去除毛刺与象脚后，对 Ø2.5 孔手工攻 M3×0.5 螺纹；装机器人前检查杯头落肩与盲孔深度，再手动交替锁紧每组螺钉。无需铜螺母或其他嵌件。杯头依靠沉孔平肩承压，Ø6.5 与 Ø3.3 之间的窄承压环不要做 C2；嘴托入口另有 C2 导入倒角。

P02 后挡、侧立挡外侧根部有 R3 圆角；P03 嘴托内侧根部为 R4、上端吊臂根部为 R3。这些结构已包含在 STEP、STL 和 3MF 中。

[查看头挡与嘴托根部细节](images/roots.png)。

## 装配与零位记录

一体 V 托要求手动调整关节后就位，不能将固定站姿的整机直接从上方一次插入。

1. 关闭电机驱动使能，确认关节能缓慢手动转动。读取编码器时可保留控制器与编码器供电。将 P01 放在平整稳固的台面。
2. 手动调整腿部，把双脚放入脚槽，再调整对应关节，使下方电机壳体面轻落到两侧 V 托，保持线束出口畅通。
3. 用两颗 M3×25 将 P02 装到立柱顶部定位键，让头部轻贴对应支撑。
4. 将 P03 从机器人前方沿水平开口槽滑入，以两颗 M3×16 固定。嘴托比模型闭嘴位置低 0.2 mm；嘴部零位以机构闭合状态确认，不强压嘴部贴上托面。
5. 安装 P04，沿前后长孔整体移动，直至一体接触面轻贴 Body，再用两颗 M3×16 固定。前桥与下方、后方支撑配合限制 Body 前倾，没有需要分别调节的接触垫。
6. 在各基准轻贴、驱动仍未使能的状态下，记录对应输出端编码器读数／偏置。不要使打印框架明显弯曲或用螺钉拉动关节就位；重复放置检查一致性后再采用标定结果。

编码器内置在电机中，标定不需要拆卸或调整编码器本体。实际电机 ID 映射及转向约定需随机器人记录。URDF 的 `q=0` 表示保存的模型站姿，不等于电机出厂编码器零位；这里记录的偏置用于建立两者对应关系。[MATLAB 回放器](../../../tools/matlab/README.md)使用模型关节坐标，不会向硬件写入零偏。

## 已检查范围

更新后的原生 CAD 每件为一个实体，所查特征无报错，默认站姿下涉及工装的静态重叠检测为零。四个最终 STL 已通过记录中的水密性、退化三角形及打印包络检查，3MF 中四个模型均与对应源 STL 在数值精度范围内一致。

上述检查针对数字文件。目前没有首件配合、结构承载、重复定位精度或整机标定的实测结果。本工装用于手动定位标定，不用于电机使能后的动作测试。

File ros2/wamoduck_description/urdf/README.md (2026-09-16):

# Why there is no `wmduck.urdf` checked in here

This directory intentionally contains no URDF file. The package builds one.

## Where the description actually comes from

| Artifact | Lives at | Stored in Git |
| --- | --- | --- |
| Canonical URDF | `models/wmduck/wmduck.urdf` | yes, once |
| 20 binary STL meshes | `models/wmduck/meshes/*.stl` | yes, once, ~11 MB |
| ROS-installable URDF | generated into the build tree, installed to `share/wamoduck_description/urdf/wmduck.urdf` | **no** |
| Build manifest | generated next to it as `wmduck.ros.manifest.json` | **no** |

`models/wmduck/` is the single source of truth. Nothing here duplicates it.

## What the build does

`CMakeLists.txt` runs `scripts/generate_ros_urdf.py` before installing, then installs the
result. The script performs exactly two things:

1. **Rewrites mesh references.** The canonical URDF says `filename="meshes/Head.stl"`.
   That path is relative to the URDF file, which is how MuJoCo-oriented tooling resolves
   it, but `robot_state_publisher` + RViz hand the string to `resource_retriever`, which
   only understands `package://`, `file://` and paths relative to the *current working
   directory*. Launch RViz from anywhere else and the robot silently renders empty. So the
   script rewrites every reference to
   `package://wamoduck_description/meshes/Head.stl`.

2. **Refuses to change anything else.** It re-parses both the source and the rewritten
   file and aborts the build if the robot name, the link count, the movable joint list (in
   document order), the fixed joint list or the root link differ. The only textual
   difference between the two files is the mesh URI prefix, which
   `wamoduck_ros2/test/test_model_contract.py` also checks independently.

No link, joint, origin, axis, limit, mass, inertia, visual or collision entry is touched, so
the ROS description and the MJCF used for training still describe the same robot.

## Why meshes are installed rather than symlinked

The alternative -- a symlink such as `meshes -> ../../models/wmduck/meshes` committed into
this package -- was rejected:

* `colcon`/`ament` install steps follow symlinks inconsistently across platforms, and
  `install(DIRECTORY)` would have to be trusted to dereference them;
* Git symlinks need `core.symlinks=true` plus the Windows "Developer Mode" / admin
  privilege to even be created on Windows, so a clone on another Windows machine can end up
  with a **text file containing a path** instead of a link. That failure mode is silent
  until RViz shows nothing.

So the build copies the meshes out of `models/wmduck/meshes` into
`share/wamoduck_description/meshes` at install time. The meshes exist exactly once inside
the Git repository; the second copy exists only in the build/install tree, which is
disposable.

## Consequence you should know about

This package needs the canonical model directory to build. Inside a full clone that
resolves automatically. If you copy only the `ros2/` subtree to another machine (for
example the RDK X5), point the build at a model directory explicitly:

```bash
colcon build --packages-select wamoduck_description \
  --cmake-args -DWAMODUCK_MODELS_DIR=/opt/wamoduck/models/wmduck
```

The build fails loudly with that instruction if `wmduck.urdf` or the mesh directory is
missing, rather than installing a description that renders an empty robot.

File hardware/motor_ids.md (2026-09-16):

# Motor IDs on the CAN-FD bus

[Home](../README.md) · English | [简体中文](motor_ids.zh-CN.md) · [Model guide](../docs/model.en.md) · [Simulation guide](../docs/simulation.md)

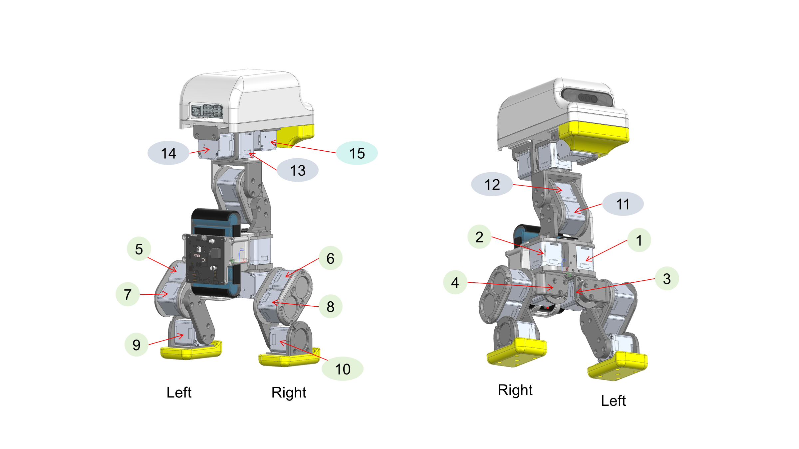
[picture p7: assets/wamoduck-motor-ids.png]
The position of each motor ID on the Wamoduck, in two CAD views


*Two CAD views of the same robot, with the bus ID printed beside each motor and `Left` / `Right` written under the legs.*

This page is **hardware and interface information only**. It records which bus ID belongs to which joint, which of the three CAN-FD buses that motor sits on, and how the 14 values a policy outputs map onto those IDs. It says nothing about whether a policy stands up or walks: every result in this repository is a simulation result, and no policy here has been tested on a physical robot.

## What is in this directory

| File | What it is |
| --- | --- |
| [motor_ids.csv](motor_ids.csv) | The mapping table, one row per motor |
| [motor_ids.json](motor_ids.json) | The same content, machine-readable |
| [../assets/wamoduck-motor-ids.png](../assets/wamoduck-motor-ids.png) | The position drawing above |

The source workbook `List_MotorID_CANFD.xlsx` and the source deck `Motor_ID_location.pptx` are **not redistributed** in this repository. Only the derived table and the exported drawing are published here.

## Three CAN-FD buses

- The **AT32** main control board runs **three physical CAN-FD buses**, each on an **XT30(2+2)** connector. That connector carries power and CAN-FD together.
- The three buses are one for the **left leg**, one for the **right leg**, and one for the **neck and head**.
- Each bus carries **5** motors, so that is **3 × 5 = 15**, which is exactly the **15** rows of the maintainer's source table. The bus split and the source table agree.
- **The three buses share one ID space, and the IDs on a single bus are not consecutive.** The left-leg bus carries IDs **1, 3, 5, 7, 9**; the right-leg bus carries **2, 4, 6, 8, 10**; the neck-and-head bus carries **11, 12, 13, 14, 15**. A left-leg bus therefore does **not** use 1, 2, 3, 4, 5. This is counter-intuitive, and it is the first thing to get right when wiring.
- That ID assignment was stated by the maintainer on **2026-09-16**, and it is the reason the source table numbers the two sides alternately.

## The mapping

| Bus | Bus ID | Joint | Chinese name | Side | In the policy action vector |
| --- | ---: | --- | --- | --- | --- |
| left_leg | 1 | `left_hip_yaw` | 左髋偏航 | left | yes |
| left_leg | 3 | `left_hip_roll` | 左髋侧摆 | left | yes |
| left_leg | 5 | `left_hip_pitch` | 左髋俯仰 | left | yes |
| left_leg | 7 | `left_knee` | 左膝关节 | left | yes |
| left_leg | 9 | `left_ankle` | 左踝关节 | left | yes |
| right_leg | 2 | `right_hip_yaw` | 右髋偏航 | right | yes |
| right_leg | 4 | `right_hip_roll` | 右髋侧摆 | right | yes |
| right_leg | 6 | `right_hip_pitch` | 右髋俯仰 | right | yes |
| right_leg | 8 | `right_knee` | 右膝关节 | right | yes |
| right_leg | 10 | `right_ankle` | 右踝关节 | right | yes |
| neck_head | 11 | `neck_pitch` | 颈俯仰 | center | yes |
| neck_head | 12 | `head_pitch` | 头俯仰 | center | yes |
| neck_head | 13 | `head_yaw` | 头偏航 | center | yes |
| neck_head | 14 | `head_roll` | 头侧倾 | center | yes |
| neck_head | 15 | `mouth` | 嘴开合 | center | **no** |

- The joint names are the names in [wmduck.urdf](../models/wmduck/wmduck.urdf). All 15 of them were checked against the URDF one by one.
- **One correction to the source.** The source table spells the bus 2 joint `Rightt_hip_yaw`. That is a typographical error: the URDF and the MJCF both spell the joint `right_hip_yaw`, and that is the spelling used here. The `note` field of [motor_ids.csv](motor_ids.csv) records the original spelling.
- **Bus ID 15 is not driven by a policy.** The published policies output **14** values, not 15: they have no beak axis. `mouth` is a real revolute joint in the URDF and a real motor on the neck-and-head bus, but it is not in the action vector, so `driven_by_policy` is `false` for it and `action_index` is empty. Bus IDs 1 to 14 are the ones a policy drives. Bus ID 15 is held back as a spare degree of freedom for interaction features, which are **planned and not implemented** — see the [roadmap](../docs/roadmap.md) for what is planned and for what the model actually contains today.

## Two different orders, and the permutation between them

There are two orders in this project, and they are **not** the same:

| Order | What it is, in order |
| --- | --- |
| Bus ID order | 1, 2, 3 ... 15 — left/right interleaved (left hip yaw, right hip yaw, left hip roll, ...) |
| Joint-tree order | left leg 5, then right leg 5, then neck and head 4 — the 14 joints a policy actuates |

The bus ID order is the order of the `<actuator>` block in [robot_walk.xml](../models/wmduck/mjcf/robot_walk.xml), the MJCF the published policies were trained in: `act_left_hip_yaw`, `act_right_hip_yaw`, `act_left_hip_roll`, and so on.

The 14-dimension action vector, however, is read as **joint-tree order**: element 0 is the left hip yaw, element 4 is the left ankle, element 5 is the right hip yaw, and elements 10 to 13 are the neck and head. That is the reading the [simulation guide](../docs/simulation.md) states, and it is the reading this repository's ROS 2 module implements since the adjudication recorded below.

**So firmware and any host program have to permute once**, from action index to bus ID:

```text
bus_id(action_index) = [1, 3, 5, 7, 9, 2, 4, 6, 8, 10, 11, 12, 13, 14]     # action index 0..13
```

Read it as: `action[0]` is the left hip yaw and goes to bus ID 1, `action[1]` is the left hip roll and goes to bus ID 3, `action[2]` is the left hip pitch and goes to bus ID 5, `action[3]` is the left knee and goes to bus ID 7, `action[4]` is the left ankle and goes to bus ID 9, `action[5]` is the right hip yaw and goes to bus ID 2, and so on; `action[10]` to `action[13]` are the neck pitch, head pitch, head yaw, and head roll, and go to bus IDs 11, 12, 13, and 14 unchanged.

> ### ⚠️ The order is settled in simulation; the permutation still has to be confirmed on the robot
>
> **What is settled.** The 14-dimension action vector is read as **joint-tree order**, as this page says. Until **2026-09-16** that was an open disagreement: this repository's ROS 2 module [`model_contract.py`](../ros2/wamoduck_ros2/wamoduck_ros2/model_contract.py) read the action vector in **actuator order** instead, which sent `action[1]` to bus ID 2 rather than bus ID 3 and disagreed for `action[1]` to `action[8]`. That module has been corrected. Four independent lines of evidence settled it:
>
> 1. **Source semantics.** mjlab's own joint resolver (`Entity.find_joints_by_actuator_names`), run against the training MJCF, returns already-joint-order ids `[0 … 13]` — the identity — because it filters the joint list in tree order and its matching call returns in that order.
> 2. **ONNX metadata.** Every published policy in [`policies/`](../policies/) records `joint_names` in its metadata as `left_hip_yaw, left_hip_roll, …, head_roll`, i.e. joint-tree order.
> 3. **A one-hot probe (direct observation).** Driving one action channel at a time through `q_target = default_joint_pos + action_scale × action` in MuJoCo, and reading which joint actually moves, gives the identity permutation: channel `i` moves joint-tree joint `i` and nothing else — every row and column has exactly one dominant entry, with dominance of at least **140×**. The actuator-order reading moves a *different* joint for `action[1]` to `action[8]`, so the two readings are physically distinguishable and this is not a matter of interpretation.
> 4. **Behaviour.** A 2×2 ablation over observation order × action order: only tree/tree stands, walks, crouches and gets up, for all five published policies; every wiring with either half swapped collapses within a second.
>
> **What is still not verified.** The permutation above has **not** been checked on a physical robot. All four lines above are simulation and source evidence; nothing here was measured on hardware. **Do not energise the servos on the strength of this permutation** until it has been confirmed on the machine — a wrong joint order mis-drives a joint, and in this project's own simulation a wrong order collapses the robot within a second. Concretely: driving one bus ID at a time on the real robot must move the joint this table names for it, and that has not been done.
>
> The three-bus topology is unverified on hardware in the same way: the **direction and polarity** of each bus, its **termination resistors**, and the ID assignment **as actually programmed into the servos** have not been checked on the machine.

## Where the drawing comes from

- The source is slide 1 of 1 in the maintainer's deck `Motor_ID_location.pptx`.
- That deck contains **two** embedded PNG renders and no others; the CAD views by themselves carry no bus IDs.
- The numbers 1 to 15 and the `Left` / `Right` labels are separate text shapes drawn over the images, so exporting the slide is the only faithful form of the annotation. The export was produced with Microsoft PowerPoint at **2400 × 1350** pixels and is published unmodified.
- The drawing is **not** a photograph of the robot, and it is not evidence that any of these motors has been wired or driven.

## What this page does not claim

- It does not claim that the robot works, or that any policy can stand or walk. It is a bus ID table.
- It does not claim that these IDs have been checked against a physical harness. No CAN bus was opened to write this page.
- Bus IDs, bus topology, joint names, and orders are interface facts. Keep them apart from behaviour results, which are on the [measured capability board](../docs/capabilities.md).

## Related pages

- [Model guide](../docs/model.en.md) — joint names, axes, and limits.
- [Simulation guide](../docs/simulation.md) — the observation layout, the joint-tree order, and the action mapping.
- [Mechanical design](README.md) — the STEP and SolidWorks files.

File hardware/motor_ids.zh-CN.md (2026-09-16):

# CAN-FD 总线上的电机 ID

[中文首页](../README.zh-CN.md) · [English](motor_ids.md) | 简体中文 · [模型指南](../docs/model.zh-CN.md) · [仿真指南](../docs/simulation.zh-CN.md)

Wamoduck 上各电机 ID 的位置，两个 CAD 视图

*同一台机器人的两个 CAD 视图，每个电机旁边标着它的总线 ID，腿部下方写着 `Left` / `Right`。*

本页是**硬件与接口信息**，仅此而已。它记录哪个总线 ID 对应哪个关节、那个电机挂在哪一条 CAN-FD 总线上，以及策略输出的 14 个值如何对应到这些 ID 上。它不涉及策略能否站起来或走起来：本仓库里的所有结果都是仿真结果，也没有任何一个策略在实物机器人上测过。

## 本目录包含什么

| 文件 | 内容 |
| --- | --- |
| [motor_ids.csv](motor_ids.csv) | 映射表，每个电机一行 |
| [motor_ids.json](motor_ids.json) | 同样内容，机器可读 |
| [../assets/wamoduck-motor-ids.png](../assets/wamoduck-motor-ids.png) | 上面那张位置图 |

源工作簿 `List_MotorID_CANFD.xlsx` 与源幻灯片 `Motor_ID_location.pptx` **不随本仓库分发**。这里只公开派生出来的表格与导出的位置图。

## 三路 CAN-FD 总线

- **AT32** 主控板走**三路物理 CAN-FD 总线**，每路都用 **XT30(2+2)** 端子。该端子把电源与 CAN-FD 一起承载。
- 三路分别是**左下肢**一路、**右下肢**一路、**脖子及头部**一路。
- 每路挂 **5** 个电机，即 **3 × 5 = 15**，恰好等于源表的 **15** 行。总线划分与源表完全吻合。
- **三路总线共用一套 ID 空间，而单条总线上的 ID 不是连号。** 左下肢总线上的 ID 是 **1、3、5、7、9**；右下肢是 **2、4、6、8、10**；脖子及头部是 **11、12、13、14、15**。也就是说，左下肢总线**不**用 1、2、3、4、5。这一点很反直觉，接线时最先要弄对的就是它。
- 该 ID 分配由维护者于 **2026-09-16** 确认，它也正是源表把左右两侧交替编号的原因。

## 映射表

| 总线 | 总线 ID | 关节 | 中文名称 | 侧 | 在策略动作向量里 |
| --- | ---: | --- | --- | --- | --- |
| left_leg | 1 | `left_hip_yaw` | 左髋偏航 | left | 是 |
| left_leg | 3 | `left_hip_roll` | 左髋侧摆 | left | 是 |
| left_leg | 5 | `left_hip_pitch` | 左髋俯仰 | left | 是 |
| left_leg | 7 | `left_knee` | 左膝关节 | left | 是 |
| left_leg | 9 | `left_ankle` | 左踝关节 | left | 是 |
| right_leg | 2 | `right_hip_yaw` | 右髋偏航 | right | 是 |
| right_leg | 4 | `right_hip_roll` | 右髋侧摆 | right | 是 |
| right_leg | 6 | `right_hip_pitch` | 右髋俯仰 | right | 是 |
| right_leg | 8 | `right_knee` | 右膝关节 | right | 是 |
| right_leg | 10 | `right_ankle` | 右踝关节 | right | 是 |
| neck_head | 11 | `neck_pitch` | 颈俯仰 | center | 是 |
| neck_head | 12 | `head_pitch` | 头俯仰 | center | 是 |
| neck_head | 13 | `head_yaw` | 头偏航 | center | 是 |
| neck_head | 14 | `head_roll` | 头侧倾 | center | 是 |
| neck_head | 15 | `mouth` | 嘴开合 | center | **否** |

- 关节名取自 [wmduck.urdf](../models/wmduck/wmduck.urdf)。这 15 个名字已逐个与 URDF 核对过。
- **对源表的一处更正。** 源表把总线 2 上的关节拼成 `Rightt_hip_yaw`。那是拼写笔误：URDF 与 MJCF 都拼作 `right_hip_yaw`，这里用的也是这个拼法。[motor_ids.csv](motor_ids.csv) 的 `note` 字段记录了源表的原始拼写。
- **总线 ID 15 不由策略驱动。** 公开策略输出的是 **14** 个值而不是 15 个：它们没有嘴部这一轴。`mouth` 在 URDF 里是真实的转动关节、在脖子及头部总线上也是真实的电机，但它不在动作向量里，因此它的 `driven_by_policy` 为 `false`、`action_index` 为空。策略驱动的是总线 ID 1 到 14。总线 ID 15 作为一个备用自由度留给交互功能，这些功能**计划中、未实现** —— 计划内容以及模型今天的实际状况见[路线图](../docs/roadmap.md)。

## 两种顺序，以及它们之间的置换

本项目里有两种顺序，而且它们**并不相同**：

| 顺序 | 具体是什么，按序展开 |
| --- | --- |
| 总线 ID 顺序 | 1、2、3 …… 15 —— 左右交错（左髋偏航、右髋偏航、左髋侧摆……） |
| 关节树顺序 | 左腿 5 个、再右腿 5 个、再颈头 4 个 —— 策略实际驱动的 14 个关节 |

总线 ID 顺序就是 [robot_walk.xml](../models/wmduck/mjcf/robot_walk.xml) 里 `<actuator>` 块的顺序 —— 也就是这些公开策略训练时所用的 MJCF：`act_left_hip_yaw`、`act_right_hip_yaw`、`act_left_hip_roll`，依此类推。

但 14 维动作向量是按**关节树顺序**解读的：第 0 个元素是左髋偏航，第 4 个是左踝，第 5 个是右髋偏航，第 10 到 13 个是颈与头。这正是[仿真指南](../docs/simulation.zh-CN.md)写明的读法，也是本仓库 ROS 2 模块在下面这条裁决之后实现的读法。

**因此固件与任何上位机程序都必须做一次置换**，从动作下标换到总线 ID：

```text
bus_id(action_index) = [1, 3, 5, 7, 9, 2, 4, 6, 8, 10, 11, 12, 13, 14]     # action index 0..13
```

读法是：`action[0]` 是左髋偏航，发往总线 ID 1；`action[1]` 是左髋侧摆，发往总线 ID 3；`action[2]` 是左髋俯仰，发往总线 ID 5；`action[3]` 是左膝，发往总线 ID 7；`action[4]` 是左踝，发往总线 ID 9；`action[5]` 是右髋偏航，发往总线 ID 2；依此类推。`action[10]` 到 `action[13]` 分别是颈俯仰、头俯仰、头偏航、头侧倾，原样发往总线 ID 11、12、13、14。

> ### ⚠️ 顺序已在仿真里裁决；置换仍需在真机上确认
>
> **已经裁决的部分。** 14 维动作向量按**关节树顺序**解读，也就是本页的读法。在 **2026-09-16** 之前这还是
> 一个悬而未决的分歧：本仓库的 ROS 2 模块 [`model_contract.py`](../ros2/wamoduck_ros2/wamoduck_ros2/model_contract.py)
> 当时把动作向量按**执行器顺序**解读，于是 `action[1]` 的目标是总线 ID 2 而不是总线 ID 3，`action[1]` 到
> `action[8]` 都与本页冲突。该模块已经改正。裁决依据是四条互相独立的证据：
>
> 1. **源码语义。** mjlab 自己的关节解析器（`Entity.find_joints_by_actuator_names`）在训练 MJCF 上直接
>    返回已按关节树顺序排列的 `[0 … 13]`，即恒等置换——它先按树序过滤关节表，匹配结果又按该表顺序返回。
> 2. **ONNX 元数据。** [`policies/`](../policies/) 里每个已发布策略的元数据 `joint_names` 都是
>    `left_hip_yaw, left_hip_roll, …, head_roll`，即关节树顺序。
> 3. **one-hot 探针（直接观测）。** 在 MuJoCo 里按 `q_target = default_joint_pos + action_scale × action`
>    逐个只给一个动作通道赋值，再看**实际动的是哪个关节**，得到的就是恒等置换：通道 `i` 只让关节树的第 `i`
>    个关节动，每行每列恰有一个主导项，主导度至少 **140×**。执行器序读法会让 `action[1]` 到 `action[8]`
>    动到**另一个**关节，所以两种读法在物理上是可区分的，不是解释问题。
> 4. **行为。** 观测顺序 × 动作顺序的 2×2 消融：只有树序／树序能站、能走、能蹲起、能起身，五个已发布策略
>    都是如此；任何一半被换掉的接线都会在一秒内瘫倒。
>
> **仍未验证的部分。** 上面这个置换**尚未**在实机上核对过。上面四条都是仿真证据与源码证据，没有任何一条
> 是在硬件上测出来的。**在机器上确认之前，不要仅凭这个置换给舵机上电**——关节顺序接错会错误驱动关节，而在
> 本项目自己的仿真里，顺序接错会让机器人在一秒内瘫倒。具体的确认方式：在真机上每次只驱动一个总线 ID，看它
> 动的是不是本表给它标的那个关节。这件事还没有做过。
>
> 三路总线的拓扑同样未在实机上验证：每一路的**方向与极性**、**终端电阻**、以及**舵机里实际烧录的 ID 分配**，
> 都还没有在机器上核对过。

## 位置图的来源

- 来源是维护者的幻灯片 `Motor_ID_location.pptx`，全套共 1 页，本图是其中的第 1 页。
- 该幻灯片里只有**两张**内嵌 PNG 渲染图，没有别的图；这两张 CAD 视图本身并不带总线 ID。
- 1 到 15 的数字与 `Left` / `Right` 标签是叠在图片之上的独立文本框，因此"把这一页导出"才是标注的唯一忠实形式。该导出由 Microsoft PowerPoint 生成，尺寸为 **2400 × 1350** 像素，原样公开、未作修改。
- 这张图**不是**实物照片，也不能作为"这些电机已经接好线或被驱动过"的证据。

## 本页没有声称的东西

- 它没有声称机器人能用，也没有声称任何策略能站能走。它只是一张总线 ID 表。
- 它没有声称这些 ID 已经在实物线束上核对过。写这一页时没有开过任何 CAN 总线。
- 总线 ID、总线拓扑、关节名与顺序都是接口事实。请把它们与行为结果分开看 —— 后者在[实测能力清单](../docs/capabilities.zh-CN.md)上。

## 相关页面

- [模型指南](../docs/model.zh-CN.md) —— 关节名、轴向与限位。
- [仿真指南](../docs/simulation.zh-CN.md) —— 观测布局、关节树顺序与动作映射。
- [机械设计](README.md) —— STEP 与 SolidWorks 文件。

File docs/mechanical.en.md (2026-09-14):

# Mechanical files

English | [简体中文](mechanical.zh-CN.md) · [Home](../README.md)

This package contains simplified geometry selected for sharing. It supports inspecting the design and using it as a starting point for changes. Manufacturing specifications and a verified assembly procedure have not yet been supplied.

## Choose a format

| Format | Location | Contents | Intended use |
| --- | --- | --- | --- |
| STEP `.stp` | [hardware/step](../hardware/step/) | 20 individual part models | Exchange geometry across CAD tools |
| SolidWorks `.SLDPRT` / `.SLDASM` | [hardware/solidworks](../hardware/solidworks/) | 20 parts + 11 assemblies | Inspect the native assembly and mates |
| URDF + STL | [models/wmduck](../models/wmduck/) | Robot description + 20 meshes | View the assembled robot and explore joint motion |
| Zero-fixture STEP / STL / 3MF | [hardware/fixtures/standing-zero](../hardware/fixtures/standing-zero/) | 4 editable STEP + 4 print STL + a two-plate H2D project | Print the standing-zero calibration fixture |

The public native set uses the main saved assembly. Alternate motion assemblies, the older-version archive, application lock files, and intermediate exports are not included. File names are preserved so they can be matched to the source model.

## STEP parts

1. Download the repository and open a file in `hardware/step/` using a CAD application that reads STEP.
2. The exports declare millimeters. Preserve the declared units and check the import scale before taking measurements.
3. These are individual parts, not a whole-robot STEP assembly. To inspect the assembled pose, use the native assembly or URDF.
4. Compare the file name with the [component inventory](components.md). Motor, battery, bearing, IMU, and control-board models provide component geometry; their presence does not provide electronics or supplier manufacturing drawings.

The STEP set is copied without changing its geometry. The IMU is represented by sheet geometry, so a successful import need not yield a solid for every file. This preparation checked file structure and declared units, but did not reopen every STEP in a CAD application.

The [structure classification](../hardware/robot-structure.csv) separates the 20 STEP geometries into 15 robot-structure classes and 5 purchased/reference classes. The assembly uses 40 modeled instances, but an assembly instance count is not a printable-part split or a manufacturing quantity. One STEP may also contain more than one body; `Body_Frame`, in particular, should be inspected as a multi-body candidate after import. CAD material assignments record source-model metadata and are not approved materials or manufacturing requirements.

## SolidWorks assembly

1. Keep all files in `hardware/solidworks/` together.
2. Open [`Full_wmduck.SLDASM`](../hardware/solidworks/Full_wmduck.SLDASM). The source export record identifies SolidWorks 2025; use that version as the initial compatibility target.
3. If SolidWorks requests referenced parts or subassemblies, resolve them from the same folder. If an imported STEP reference is requested, inspect `hardware/step/`.
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

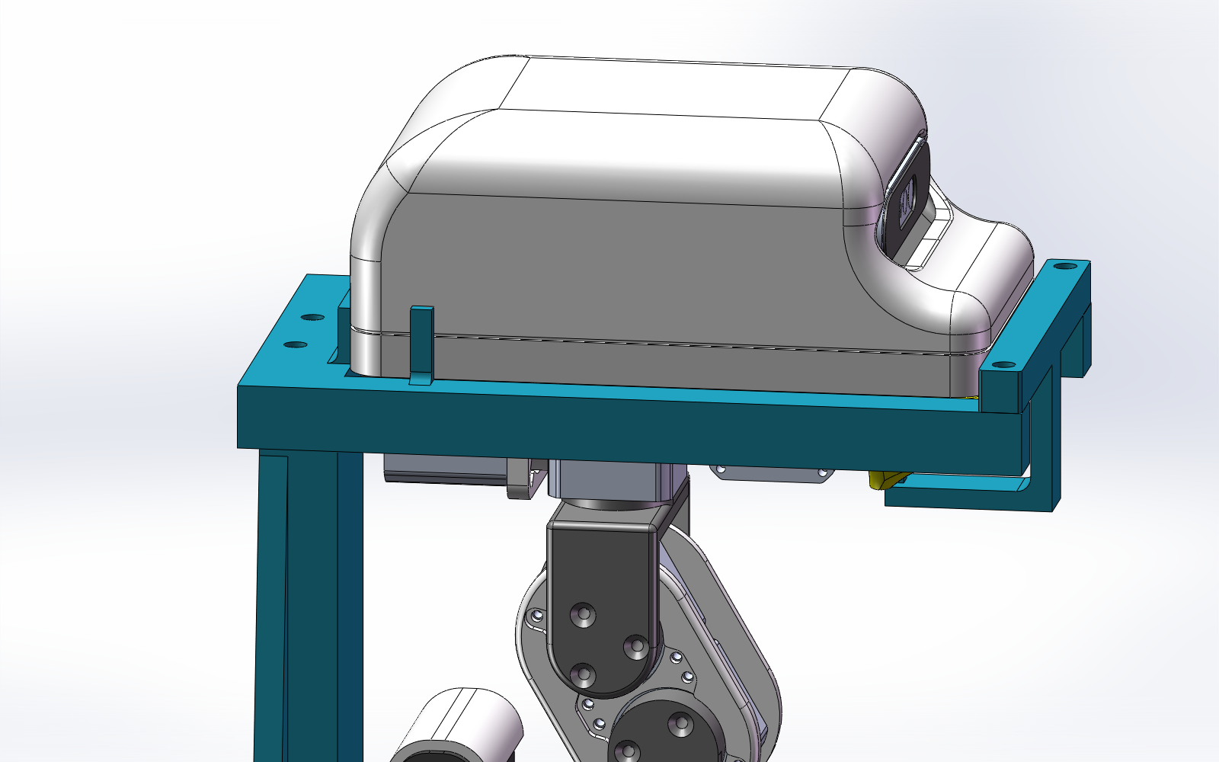
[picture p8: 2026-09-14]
hardware/fixtures/standing-zero/images/roots.png

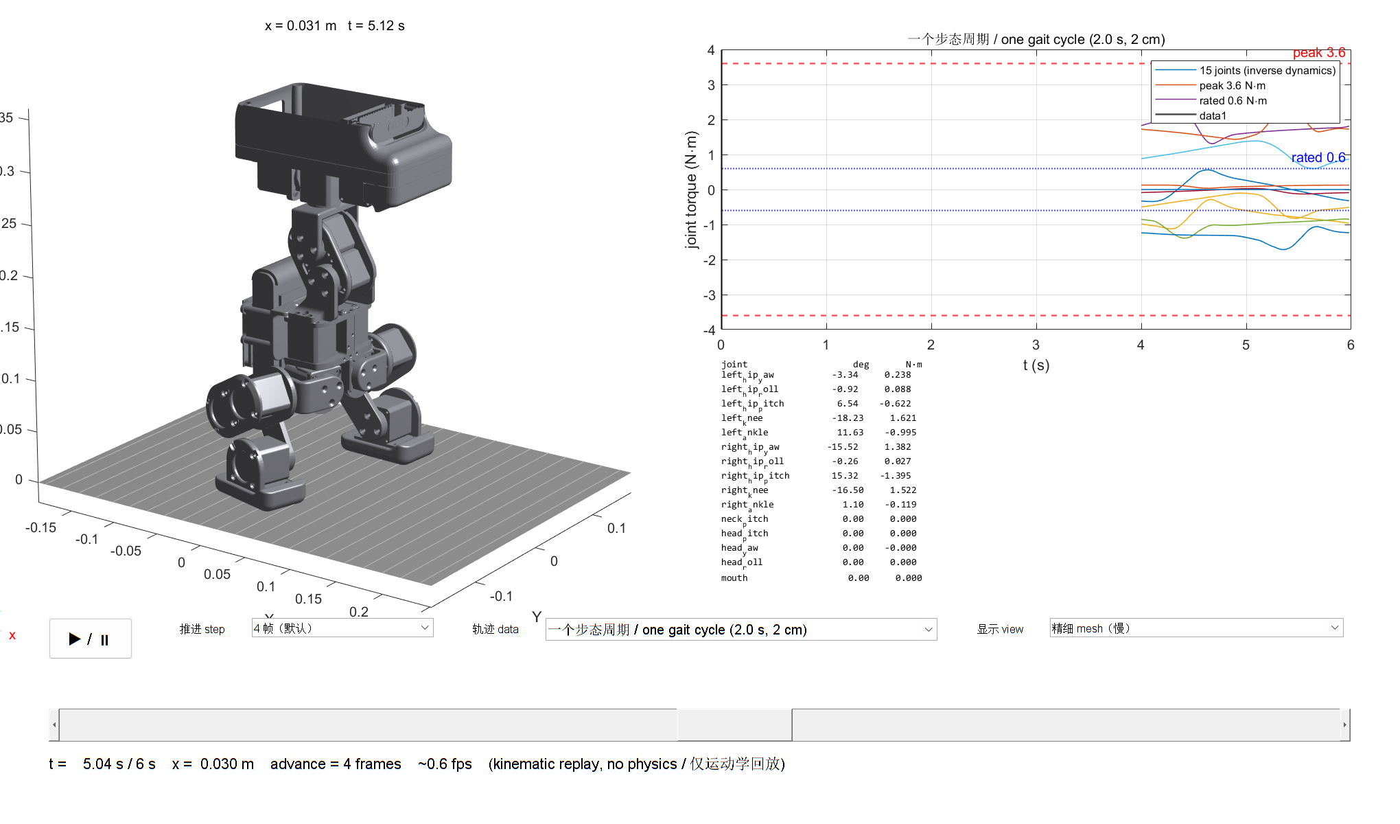
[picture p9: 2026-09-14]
assets/wamoduck-matlab-player.png

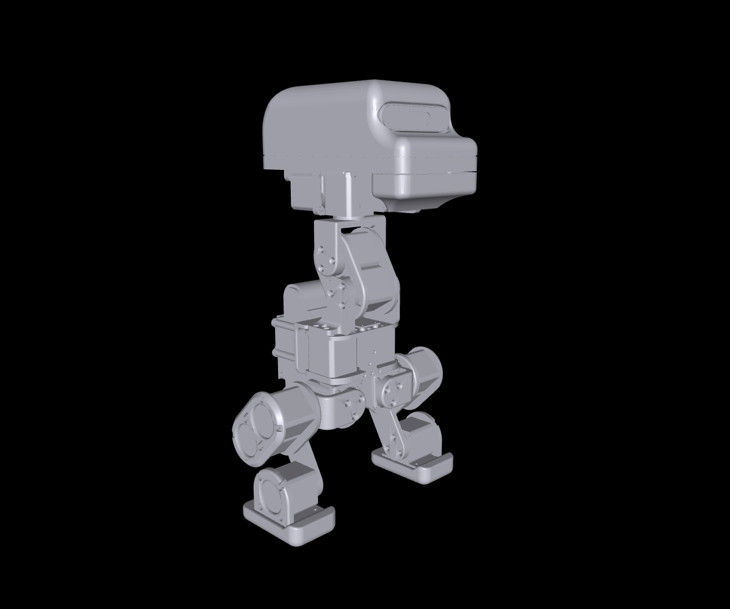
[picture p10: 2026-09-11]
assets/wamoduck-model.png

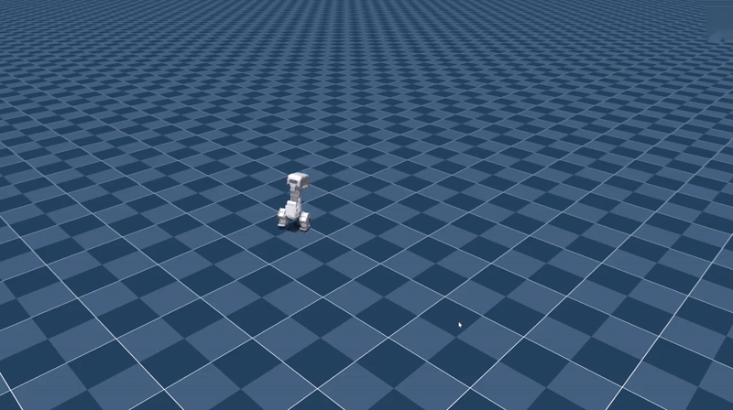
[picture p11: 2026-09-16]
assets/wamoduck-getup-struggle.gif

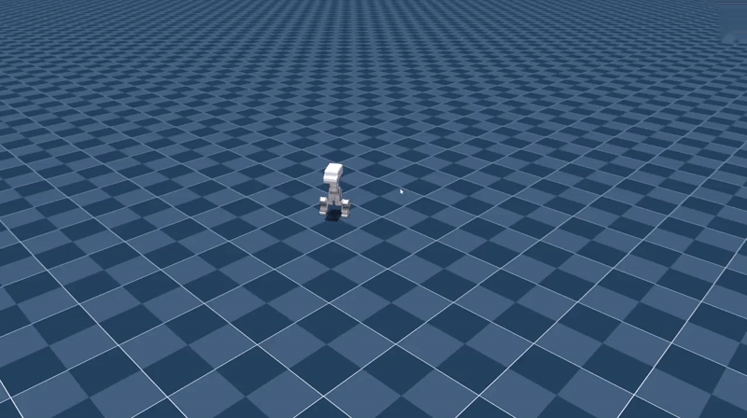
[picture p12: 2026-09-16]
assets/wamoduck-push-normal.gif

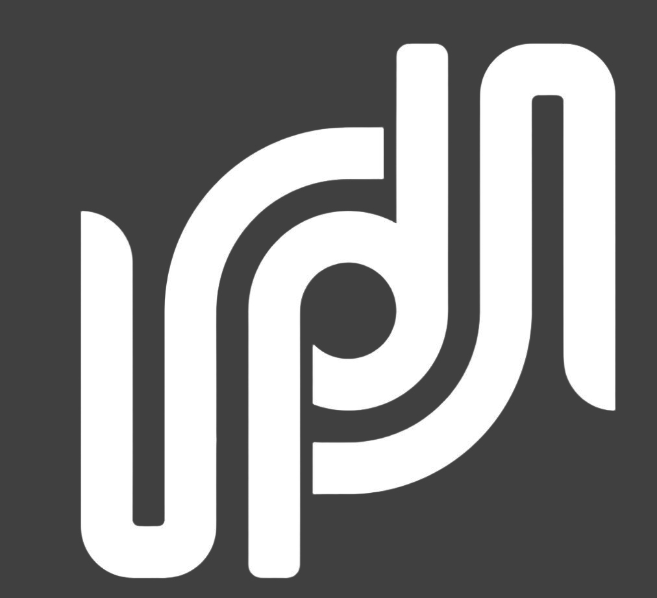
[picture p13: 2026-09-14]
assets/branding/wamotech-symbol-white.png

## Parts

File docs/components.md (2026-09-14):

# Component inventory / 组件清单

[English home](../README.md) · [中文首页](../README.zh-CN.md)

This is a count of instances in the simplified model, **not a procurement or manufacturing BOM**. There are 40 modeled instances using 20 unique part geometries. Fasteners, cables, connectors, inserts, and unmodeled parts must be inventoried separately. / 这是简化模型中的实例数量，**不是采购或制造 BOM**：共 40 个实例、20 种零件几何。紧固件、线束、连接器、嵌件及未建模零件仍需单独盘点。

Counts are derived from [component_mass_audit.csv](../models/wmduck/component_mass_audit.csv). The linked STEP files and identically named native part files describe the same named components; this does not establish manufacturing readiness. / 数量来自 [component_mass_audit.csv](../models/wmduck/component_mass_audit.csv)。下表 STEP 与同名原生零件对应同一命名组件，不代表已经具备制造条件。

The machine-readable [STEP classification](../hardware/robot-structure.csv) identifies 15 robot-structure geometry classes and 5 purchased/reference classes (`Motor_HTDW3532`, `Bearing_20_27_4`, `Battery_6s18650_24V`, `Control_Borad_AT32`, and `IMU_YB-MRA02`). This classification describes the role of each model, not its manufacturing process. Modeled instances are not printable-part splits: a single model such as `Body_Frame` may contain multiple bodies, while several assembly instances may reuse one geometry. CAD material labels are source-model metadata, not manufacturing requirements. / 机器可读的 [STEP 分类表](../hardware/robot-structure.csv)标出 15 类机器人结构几何与 5 类外购／参考几何（`Motor_HTDW3532`、`Bearing_20_27_4`、`Battery_6s18650_24V`、`Control_Borad_AT32`、`IMU_YB-MRA02`）。该分类描述模型用途，不代表制造工艺。建模实例数不等于打印分体数：`Body_Frame` 这类单个模型可能包含多个实体，而装配中的多个实例也可能复用同一几何。CAD 材料标签属于源模型元数据，不是制造要求。

| STEP file / STEP 文件 | Description / 说明 | Instances / 实例数 | Modeled link(s) / 所属模型刚体 |
| --- | --- | ---: | --- |
| [Battery_6s18650_24V.stp](../hardware/step/Battery_6s18650_24V.stp) | Battery envelope / 电池包外形 | 1 | `base_link` |
| [Bearing_20_27_4.stp](../hardware/step/Bearing_20_27_4.stp) | Bearing geometry / 轴承几何 | 2 | `neck_pitch_link` |
| [Body_Frame.stp](../hardware/step/Body_Frame.stp) | Body frame / 躯干框架 | 1 | `base_link` |
| [Control_Borad_AT32.stp](../hardware/step/Control_Borad_AT32.stp) | Control-board envelope / 控制板外形 | 1 | `base_link` |
| [Head.stp](../hardware/step/Head.stp) | Head / 头部 | 1 | `head_roll_link` |
| [Head_pitch.stp](../hardware/step/Head_pitch.stp) | Head pitch part / 头部俯仰构件 | 1 | `head_pitch_link` |
| [IMU_YB-MRA02.stp](../hardware/step/IMU_YB-MRA02.stp) | IMU envelope / IMU 外形 | 1 | `base_link` |
| [Left_feet.stp](../hardware/step/Left_feet.stp) | Left foot / 左脚 | 1 | `left_ankle_link` |
| [Left_hip_roll.stp](../hardware/step/Left_hip_roll.stp) | Left hip roll part / 左髋侧摆构件 | 1 | `left_hip_roll_link` |
| [Left_knee.stp](../hardware/step/Left_knee.stp) | Left knee part / 左膝构件 | 1 | `left_knee_link` |
| [Motor_HTDW3532.stp](../hardware/step/Motor_HTDW3532.stp) | Motor envelope / 电机外形 | 15 | Distributed across the robot / 分布于整机 |
| [Mouth.stp](../hardware/step/Mouth.stp) | Beak / 嘴部 | 1 | `mouth_link` |
| [Right_feet.stp](../hardware/step/Right_feet.stp) | Right foot / 右脚 | 1 | `right_ankle_link` |
| [Right_hip_roll.stp](../hardware/step/Right_hip_roll.stp) | Right hip roll part / 右髋侧摆构件 | 1 | `right_hip_roll_link` |
| [Right_knee.stp](../hardware/step/Right_knee.stp) | Right knee part / 右膝构件 | 1 | `right_knee_link` |
| [WMD1005.stp](../hardware/step/WMD1005.stp) | Numbered structural part / 编号结构件 | 3 | `head_yaw_link`, `left_hip_yaw_link`, `right_hip_yaw_link` |
| [WMD1007.stp](../hardware/step/WMD1007.stp) | Numbered structural part / 编号结构件 | 3 | `left_hip_pitch_link`, `neck_pitch_link`, `right_hip_pitch_link` |
| [WMD1008.stp](../hardware/step/WMD1008.stp) | Numbered structural part / 编号结构件 | 2 | `left_hip_pitch_link`, `right_hip_pitch_link` |
| [WMD1012.stp](../hardware/step/WMD1012.stp) | Numbered structural part / 编号结构件 | 1 | `neck_pitch_link` |
| [WMD1018.stp](../hardware/step/WMD1018.stp) | Numbered structural part / 编号结构件 | 1 | `head_roll_link` |

**Total / 合计：40 instances / 个实例。**

A part assigned to a link moves rigidly with that link. The table does not identify motor IDs, encoder wiring, or procurement quantities for a complete robot. / 某零件归属于一个 link，表示它与该刚体一起运动；此表不定义电机 ID、编码器接线，也不代表完整机器人的采购数量。

## Printable calibration fixture / 可打印标定工装

The [standing-zero fixture](../hardware/fixtures/standing-zero/README.md) is a separate manufacturing package and is not part of the 40 robot-model instances above. Print one each of its four millimetre-scale STL files: main frame, head cradle, combined head keeper/mouth stop, and Body bridge. Four matching STEP files provide editable exchange geometry. The user-supplied Bambu H2D 3MF places the four parts on two plates, and assembly uses six M3 screws. The package does not claim a completed physical print or measured repeatability. / [站姿零点工装](../hardware/fixtures/standing-zero/README.zh-CN.md)是独立制造包，不属于上面的 40 个机器人模型实例。其 4 个毫米单位 STL——主框架、头托、头部前挡／嘴托组合件和 Body 横梁——每种打印 1 件；另有 4 个对应 STEP 用于编辑交换。用户提供的 Bambu H2D 3MF 将四件排在两个打印盘上，装配使用 6 颗 M3 螺钉。本包不宣称已经完成实物打印或实测重复定位验证。

## Before making a purchasing BOM / 转为采购 BOM 前

- Confirm exact supplier part numbers and mechanical/electrical compatibility. File names are identifiers, not purchasing specifications. / 确认供应商完整型号及机械／电气兼容性；文件名是标识，不是采购规格。
- Add omitted hardware and record quantities, material/finish, alternatives, and revision. / 补齐未建模配件，记录数量、材料／表面处理、替代项及版本。
- Separate purchased components from parts to fabricate, then verify dimensions and assembly fits. / 区分外购部件与需要加工的零件，再核对尺寸与装配配合。
- Reconcile CAD masses with measured values. The head is currently assigned aluminum, the battery resin, and the IMU zero mass. / 用实测值核对 CAD 质量；当前头部使用铝合金材料、电池使用树脂材料，IMU 质量为零。

See the [English model guide](model.en.md) / [中文模型指南](model.zh-CN.md) for the mass assumptions and [roadmap](roadmap.md) for build documentation work. / 质量假设见模型指南，搭建资料的后续工作见路线图。

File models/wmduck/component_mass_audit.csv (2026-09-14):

component | link | mass_kg | cad_mass_kg | cad_density_kg_m3 | material | mass_override | cad_mass_override | inertia_scale | com_source | inertia_source | mass_source
Body-1/Motor_HTDW3532-1 | base_link | 0.141 | 0.11414916694039093 | 2700.0 | ['6061 合金', 'solidworks materials'] | True | False | 1.235225834575128 | CAD | estimated: CAD inertia scaled by mass ratio | motor_parameters.json: maintainer measurement 2026-09-14 (all 15 instances)
Body-1/Body_Frame-2 | base_link | 0.13050781347395807 | 0.13050781347395807 | 1020.0 | ['ABS', 'solidworks materials'] | False | False | 1.0 | CAD | CAD | CAD
Body-1/IMU_YB-MRA02-1 | base_link | 0.0 | 0.0 | 0.0 | ['聚脂树脂', 'solidworks materials'] | False | False | 1.0 | CAD | CAD | CAD
Body-1/Control_Borad_AT32-1 | base_link | 0.007232666071029665 | 0.007232666071029665 | 1160.0 | ['聚脂树脂', 'solidworks materials'] | False | False | 1.0 | CAD | CAD | CAD
Body-1/Motor_HTDW3532-2 | base_link | 0.141 | 0.11414916694039093 | 2700.0 | ['6061 合金', 'solidworks materials'] | True | False | 1.235225834575128 | CAD | estimated: CAD inertia scaled by mass ratio | motor_parameters.json: maintainer measurement 2026-09-14 (all 15 instances)
Body-1/Battery_6s18650_24V-1 | base_link | 0.23089975563519718 | 0.23089975563519718 | 1099.9999999999998 | ['环氧树脂,未充填', 'solidworks materials'] | False | False | 1.0 | CAD | CAD | CAD
Left_hip_yaw-1/Motor_HTDW3532-1 | left_hip_yaw_link | 0.141 | 0.11414916694039093 | 2700.0 | ['6061 合金', 'solidworks materials'] | True | False | 1.235225834575128 | CAD | estimated: CAD inertia scaled by mass ratio | motor_parameters.json: maintainer measurement 2026-09-14 (all 15 instances)
Left_hip_yaw-1/WMD1005-1 | left_hip_yaw_link | 0.010466330426084794 | 0.010466330426084794 | 1020.0 | ['ABS', 'solidworks materials'] | False | False | 1.0 | CAD | CAD | CAD
Right_hip_yaw-1/Motor_HTDW3532-1 | right_hip_yaw_link | 0.141 | 0.11414916694039093 | 2700.0 | ['6061 合金', 'solidworks materials'] | True | False | 1.235225834575128 | CAD | estimated: CAD inertia scaled by mass ratio | motor_parameters.json: maintainer measurement 2026-09-14 (all 15 instances)
Right_hip_yaw-1/WMD1005-1 | right_hip_yaw_link | 0.010466330426084794 | 0.010466330426084794 | 1020.0 | ['ABS', 'solidworks materials'] | False | False | 1.0 | CAD | CAD | CAD
Left_hip_roll-1 | left_hip_roll_link | 0.024550028562929826 | 0.024550028562929826 | 1020.0 | ['ABS', 'solidworks materials'] | False | False | 1.0 | CAD | CAD | CAD
Right_hip_roll-1 | right_hip_roll_link | 0.024550028563035134 | 0.024550028563035134 | 1020.0 | ['ABS', 'solidworks materials'] | False | False | 1.0 | CAD | CAD | CAD
Left_hip_pitch-1/WMD1007-1 | left_hip_pitch_link | 0.011245589395471869 | 0.011245589395471869 | 1020.0000000000001 | ['ABS', 'solidworks materials'] | False | False | 1.0 | CAD | CAD | CAD
Left_hip_pitch-1/Motor_HTDW3532-1 | left_hip_pitch_link | 0.141 | 0.11414916694039093 | 2700.0 | ['6061 合金', 'solidworks materials'] | True | False | 1.235225834575128 | CAD | estimated: CAD inertia scaled by mass ratio | motor_parameters.json: maintainer measurement 2026-09-14 (all 15 instances)
Left_hip_pitch-1/Motor_HTDW3532-2 | left_hip_pitch_link | 0.141 | 0.11414916694039093 | 2700.0 | ['6061 合金', 'solidworks materials'] | True | False | 1.235225834575128 | CAD | estimated: CAD inertia scaled by mass ratio | motor_parameters.json: maintainer measurement 2026-09-14 (all 15 instances)
Left_hip_pitch-1/WMD1008-1 | left_hip_pitch_link | 0.016132138578650264 | 0.016132138578650264 | 1019.9999999999999 | ['ABS', 'solidworks materials'] | False | False | 1.0 | CAD | CAD | CAD
Rightt_hip_pitch-1/Motor_HTDW3532-1 | right_hip_pitch_link | 0.141 | 0.11414916694039093 | 2700.0 | ['6061 合金', 'solidworks materials'] | True | False | 1.235225834575128 | CAD | estimated: CAD inertia scaled by mass ratio | motor_parameters.json: maintainer measurement 2026-09-14 (all 15 instances)
Rightt_hip_pitch-1/Motor_HTDW3532-2 | right_hip_pitch_link | 0.141 | 0.11414916694039093 | 2700.0 | ['6061 合金', 'solidworks materials'] | True | False | 1.235225834575128 | CAD | estimated: CAD inertia scaled by mass ratio | motor_parameters.json: maintainer measurement 2026-09-14 (all 15 instances)
Rightt_hip_pitch-1/WMD1008-1 | right_hip_pitch_link | 0.016132138578650264 | 0.016132138578650264 | 1019.9999999999999 | ['ABS', 'solidworks materials'] | False | False | 1.0 | CAD | CAD | CAD
Rightt_hip_pitch-1/WMD1007-1 | right_hip_pitch_link | 0.011245589395471869 | 0.011245589395471869 | 1020.0000000000001 | ['ABS', 'solidworks materials'] | False | False | 1.0 | CAD | CAD | CAD
Left_knee-1 | left_knee_link | 0.02108161159428854 | 0.02108161159428854 | 1020.0 | ['ABS', 'solidworks materials'] | False | False | 1.0 | CAD | CAD | CAD
Right_knee-1 | right_knee_link | 0.021081611594288615 | 0.021081611594288615 | 1020.0 | ['ABS', 'solidworks materials'] | False | False | 1.0 | CAD | CAD | CAD
Left_ankle-1/Left_feet-1 | left_ankle_link | 0.07567167504306375 | 0.07567167504306375 | 1020.0 | ['ABS', 'solidworks materials'] | False | False | 1.0 | CAD | CAD | CAD
Left_ankle-1/Motor_HTDW3532-1 | left_ankle_link | 0.141 | 0.11414916694039093 | 2700.0 | ['6061 合金', 'solidworks materials'] | True | False | 1.235225834575128 | CAD | estimated: CAD inertia scaled by mass ratio | motor_parameters.json: maintainer measurement 2026-09-14 (all 15 instances)
Right_ankle-1/Right_feet-1 | right_ankle_link | 0.07567167504161111 | 0.07567167504161111 | 1020.0000000000001 | ['ABS', 'solidworks materials'] | False | False | 1.0 | CAD | CAD | CAD
Right_ankle-1/Motor_HTDW3532-1 | right_ankle_link | 0.141 | 0.11414916694039093 | 2700.0 | ['6061 合金', 'solidworks materials'] | True | False | 1.235225834575128 | CAD | estimated: CAD inertia scaled by mass ratio | motor_parameters.json: maintainer measurement 2026-09-14 (all 15 instances)
Neck_pitch-1/Motor_HTDW3532-1 | neck_pitch_link | 0.141 | 0.11414916694039093 | 2700.0 | ['6061 合金', 'solidworks materials'] | True | False | 1.235225834575128 | CAD | estimated: CAD inertia scaled by mass ratio | motor_parameters.json: maintainer measurement 2026-09-14 (all 15 instances)
Neck_pitch-1/WMD1012-1 | neck_pitch_link | 0.01854766553377453 | 0.01854766553377453 | 1020.0000000000001 | ['ABS', 'solidworks materials'] | False | False | 1.0 | CAD | CAD | CAD
Neck_pitch-1/WMD1007-1 | neck_pitch_link | 0.011245589395471869 | 0.011245589395471869 | 1020.0000000000001 | ['ABS', 'solidworks materials'] | False | False | 1.0 | CAD | CAD | CAD
Neck_pitch-1/Bearing_20_27_4-1 | neck_pitch_link | 0.007807988716741449 | 0.007807988716741449 | 8000.0 | ['锻制不锈钢', 'solidworks materials'] | False | False | 1.0 | CAD | CAD | CAD
Neck_pitch-1/Bearing_20_27_4-2 | neck_pitch_link | 0.007807988716741449 | 0.007807988716741449 | 8000.0 | ['锻制不锈钢', 'solidworks materials'] | False | False | 1.0 | CAD | CAD | CAD
Neck_pitch-1/Motor_HTDW3532-2 | neck_pitch_link | 0.141 | 0.11414916694039093 | 2700.0 | ['6061 合金', 'solidworks materials'] | True | False | 1.235225834575128 | CAD | estimated: CAD inertia scaled by mass ratio | motor_parameters.json: maintainer measurement 2026-09-14 (all 15 instances)
Head_pitch-1 | head_pitch_link | 0.03678539064270743 | 0.03678539064270743 | 1020.0000000000001 | ['ABS', 'solidworks materials'] | False | False | 1.0 | CAD | CAD | CAD
Head_yaw-1/WMD1005-1 | head_yaw_link | 0.010466330426084794 | 0.010466330426084794 | 1020.0 | ['ABS', 'solidworks materials'] | False | False | 1.0 | CAD | CAD | CAD
Head_yaw-1/Motor_HTDW3532-1 | head_yaw_link | 0.141 | 0.11414916694039093 | 2700.0 | ['6061 合金', 'solidworks materials'] | True | False | 1.235225834575128 | CAD | estimated: CAD inertia scaled by mass ratio | motor_parameters.json: maintainer measurement 2026-09-14 (all 15 instances)
Head_roll-1/WMD1018-1 | head_roll_link | 0.025396410469406706 | 0.025396410469406706 | 1020.0 | ['ABS', 'solidworks materials'] | False | False | 1.0 | CAD | CAD | CAD
Head_roll-1/Head-1 | head_roll_link | 0.7734440714605136 | 0.7734440714605136 | 2700.0 | ['6061 合金', 'solidworks materials'] | False | False | 1.0 | CAD | CAD | CAD
Head_roll-1/Motor_HTDW3532-2 | head_roll_link | 0.141 | 0.11414916694039093 | 2700.0 | ['6061 合金', 'solidworks materials'] | True | False | 1.235225834575128 | CAD | estimated: CAD inertia scaled by mass ratio | motor_parameters.json: maintainer measurement 2026-09-14 (all 15 instances)
Head_roll-1/Motor_HTDW3532-1 | head_roll_link | 0.141 | 0.11414916694039093 | 2700.0 | ['6061 合金', 'solidworks materials'] | True | False | 1.235225834575128 | CAD | estimated: CAD inertia scaled by mass ratio | motor_parameters.json: maintainer measurement 2026-09-14 (all 15 instances)
Mouth-1 | mouth_link | 0.05790336561061501 | 0.05790336561061501 | 1020.0 | ['ABS', 'solidworks materials'] | False | False | 1.0 | CAD | CAD | CAD

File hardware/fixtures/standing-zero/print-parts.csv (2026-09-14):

part | stl | quantity | plate | material | nozzle_mm | layer_height_mm | walls | infill | infill_pattern | brim_type | brim_width_mm | bed | support | print_orientation
P01_Main_frame | stl/P01_Main_frame.stl | 1 | 1 | PLA | 0.4 | 0.2 | 2 | 20% | honeycomb | auto_brim | 5 | SuperTack | normal(auto), enabled | as exported; bbox minimum translated to XYZ 0
P02_Head_cradle | stl/P02_Head_cradle.stl | 1 | 2 | PLA | 0.4 | 0.2 | 2 | 20% | honeycomb | auto_brim | 5 | SuperTack | normal(auto), enabled | bottom face down
P03_Head_keeper_mouth | stl/P03_Head_keeper_mouth.stl | 1 | 2 | PLA | 0.4 | 0.2 | 2 | 20% | honeycomb | auto_brim | 5 | SuperTack | normal(auto), enabled | outer X=110.5 face down
P04_Body_bridge | stl/P04_Body_bridge.stl | 1 | 2 | PLA | 0.4 | 0.2 | 2 | 20% | honeycomb | auto_brim | 5 | SuperTack | normal(auto), enabled | Y=-32 side face down

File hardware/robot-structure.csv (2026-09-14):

file | category | modeled_instances | modeled_links | cad_material_label | manufacturing_status
Battery_6s18650_24V.stp | purchased_reference | 1 | base_link | Unfilled epoxy resin | Battery envelope only; do not treat as a printed pack design
Bearing_20_27_4.stp | purchased_reference | 2 | neck_pitch_link | Forged stainless steel | Purchased bearing reference geometry
Body_Frame.stp | robot_structure | 1 | base_link | ABS | Manufacturing route unverified; may import as multiple bodies
Control_Borad_AT32.stp | purchased_reference | 1 | base_link | Polyester resin | Control-board envelope only; not PCB manufacturing data
Head.stp | robot_structure | 1 | head_roll_link | 6061 alloy | Structural geometry; CAD label does not authorize FDM substitution
Head_pitch.stp | robot_structure | 1 | head_pitch_link | ABS | Manufacturing route unverified
IMU_YB-MRA02.stp | purchased_reference | 1 | base_link | Polyester resin | Surface-only IMU envelope; not a printable sensor
Left_feet.stp | robot_structure | 1 | left_ankle_link | ABS | Manufacturing route unverified
Left_hip_roll.stp | robot_structure | 1 | left_hip_roll_link | ABS | Manufacturing route unverified
Left_knee.stp | robot_structure | 1 | left_knee_link | ABS | Manufacturing route unverified
Motor_HTDW3532.stp | purchased_reference | 15 | distributed across robot | 6061 alloy | Purchased motor/gearbox reference envelope
Mouth.stp | robot_structure | 1 | mouth_link | ABS | Manufacturing route unverified
Right_feet.stp | robot_structure | 1 | right_ankle_link | ABS | Manufacturing route unverified
Right_hip_roll.stp | robot_structure | 1 | right_hip_roll_link | ABS | Manufacturing route unverified
Right_knee.stp | robot_structure | 1 | right_knee_link | ABS | Manufacturing route unverified
WMD1005.stp | robot_structure | 3 | head_yaw_link; left_hip_yaw_link; right_hip_yaw_link | ABS | Manufacturing route unverified
WMD1007.stp | robot_structure | 3 | left_hip_pitch_link; neck_pitch_link; right_hip_pitch_link | ABS | Manufacturing route unverified
WMD1008.stp | robot_structure | 2 | left_hip_pitch_link; right_hip_pitch_link | ABS | Manufacturing route unverified
WMD1012.stp | robot_structure | 1 | neck_pitch_link | ABS | Manufacturing route unverified
WMD1018.stp | robot_structure | 1 | head_roll_link | ABS | Manufacturing route unverified

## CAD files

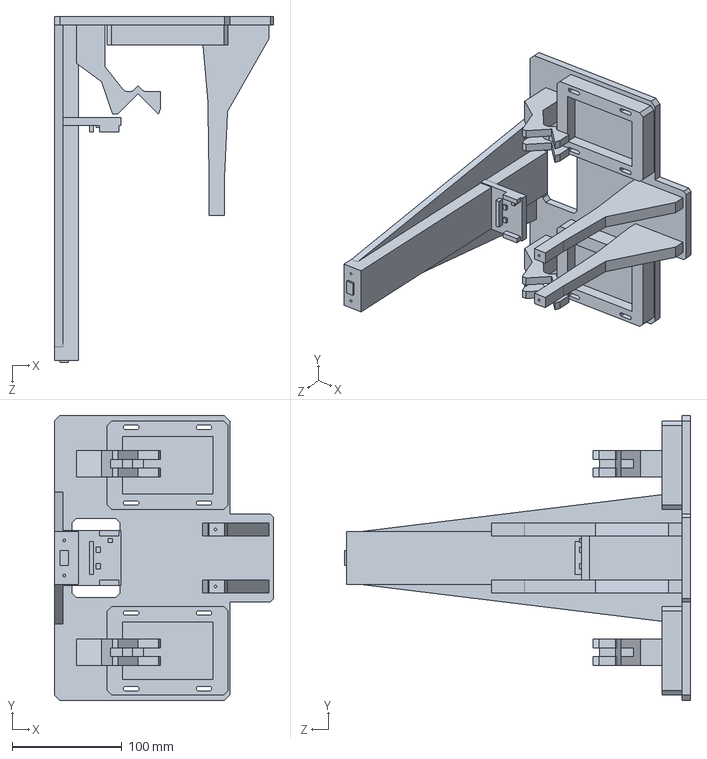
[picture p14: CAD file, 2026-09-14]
hardware/fixtures/standing-zero/step/P01_Main_frame.step
200.0 x 260.0 x 315.8 mm

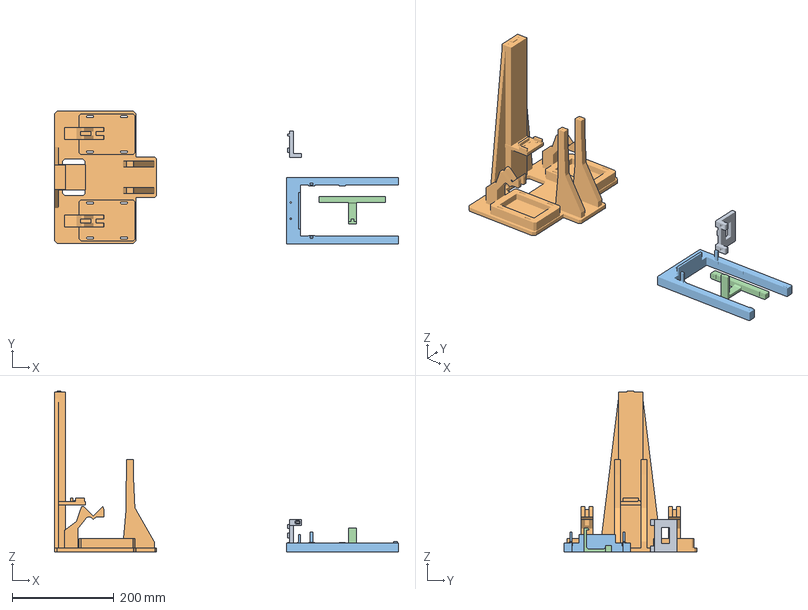
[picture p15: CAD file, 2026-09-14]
hardware/fixtures/standing-zero/bambu/H2D_PLA_standing_zero.3mf
675.9 x 260.7 x 315.8 mm
P04_Body_bridge.stl
P01_Main_frame.stl
P02_Head_cradle.stl
P03_Head_keeper_mouth.stl

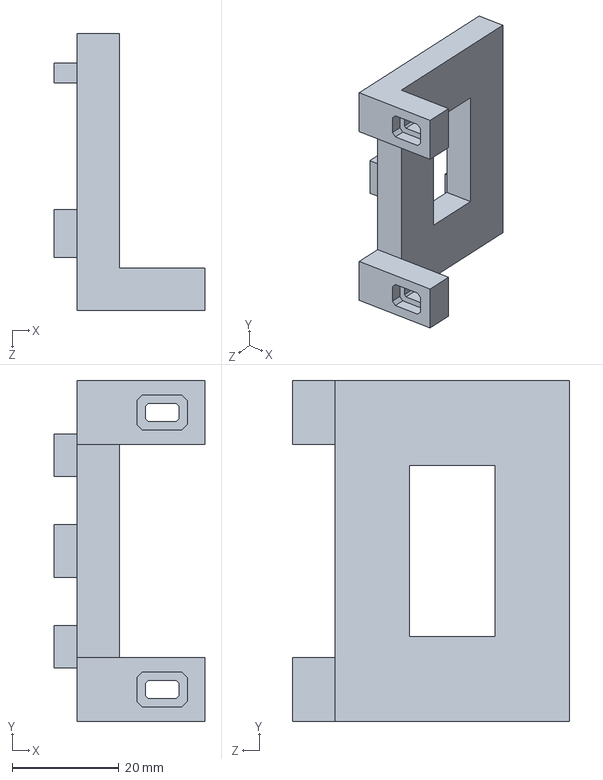
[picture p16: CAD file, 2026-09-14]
hardware/fixtures/standing-zero/step/P04_Body_bridge.step
28.2 x 64.0 x 52.0 mm

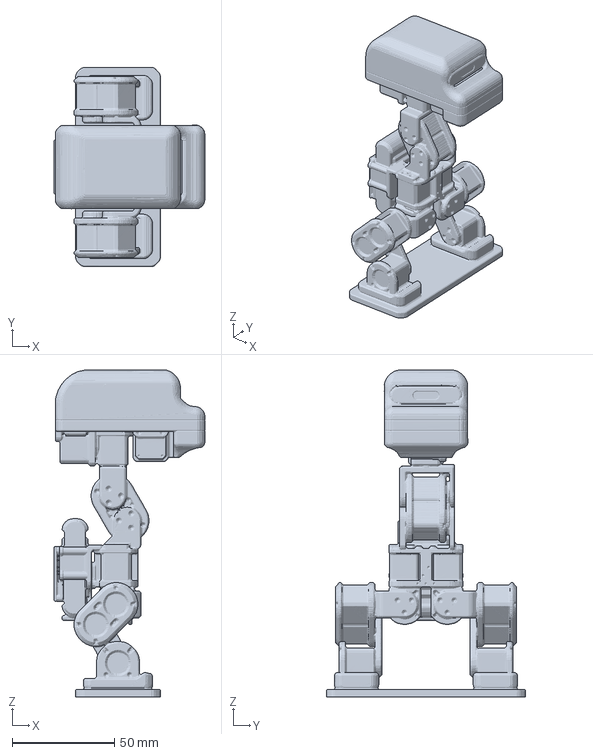
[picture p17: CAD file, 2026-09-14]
hardware/printable/wamoduck-a1mini-standing/Wamoduck_Standing_160mm.3mf
73.9 x 97.6 x 160.0 mm

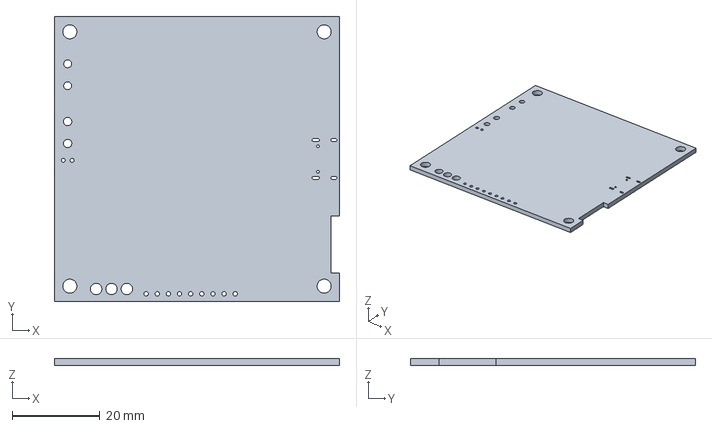
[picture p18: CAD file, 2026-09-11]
hardware/step/Control_Borad_AT32.stp
65.0 x 65.0 x 1.51 mm

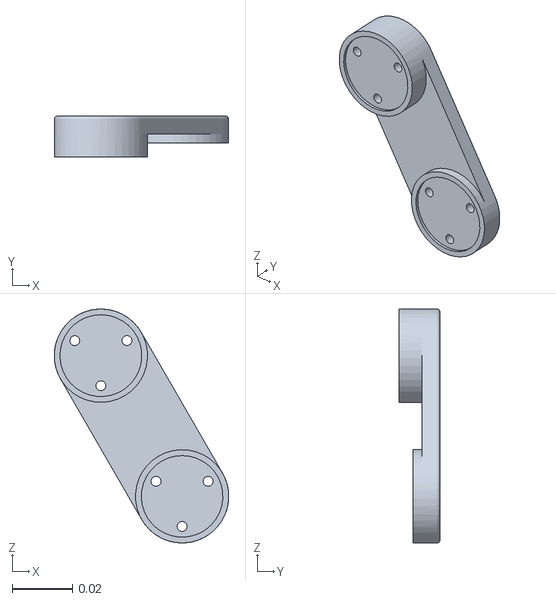
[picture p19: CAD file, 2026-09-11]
models/wmduck/meshes/Right_knee.stl
0.058 x 0.0136 x 0.0778

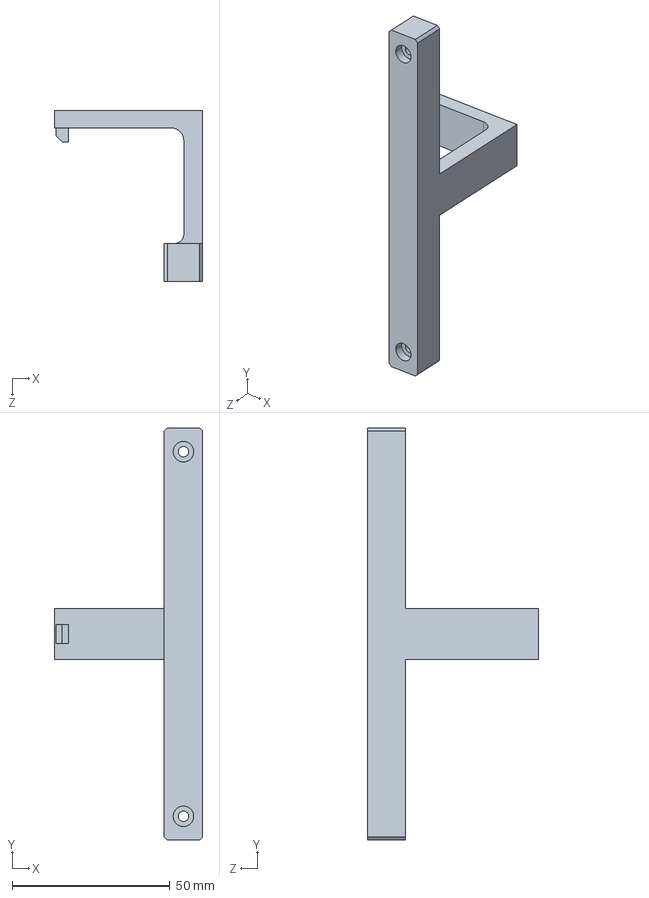
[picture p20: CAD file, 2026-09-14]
hardware/fixtures/standing-zero/step/P03_Head_keeper_mouth.step
47.0 x 130.4 x 54.1 mm

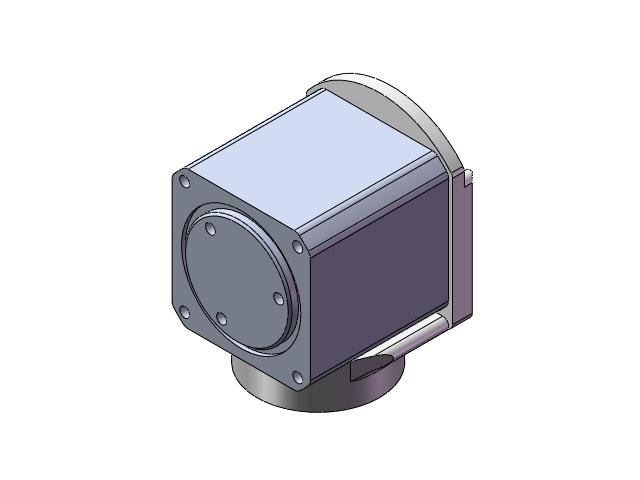
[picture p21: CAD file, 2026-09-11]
hardware/solidworks/Head_yaw.SLDASM
Motor_HTDW3532
WMD1005

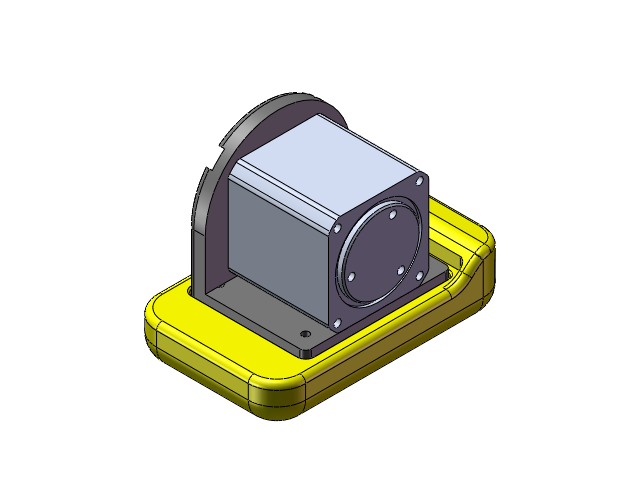
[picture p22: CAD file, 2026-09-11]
hardware/solidworks/Left_ankle.SLDASM
Left_feet
Motor_HTDW3532

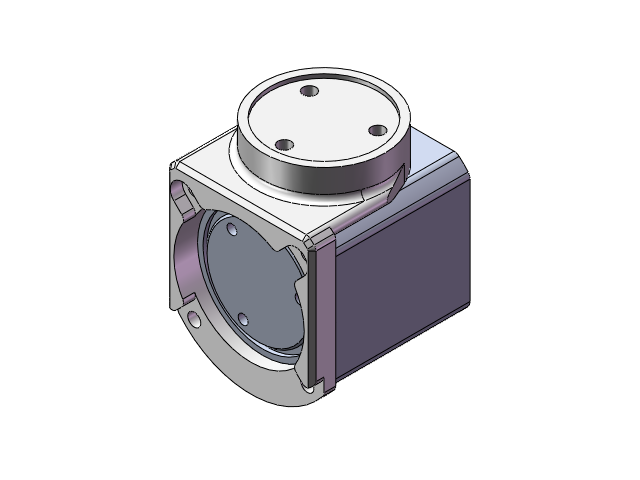
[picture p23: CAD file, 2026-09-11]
hardware/solidworks/Right_hip_yaw.SLDASM
Motor_HTDW3532
WMD1005

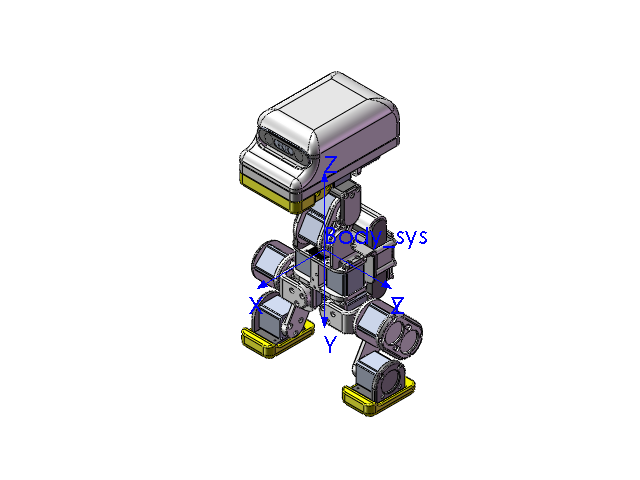
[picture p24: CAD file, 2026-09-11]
hardware/solidworks/Full_wmduck.SLDASM
Body_Frame
IMU_YB-MRA02
Battery_6s18650_24V
Control_Borad_AT32
Motor_HTDW3532 x 15
WMD1005 x 3
Left_hip_roll
Right_hip_roll
WMD1007 x 3
WMD1008 x 2
Left_knee
Right_knee
Left_feet
Right_feet
WMD1012
Bearing_20_27_4 x 2
Head_pitch
WMD1018
Head
Mouth

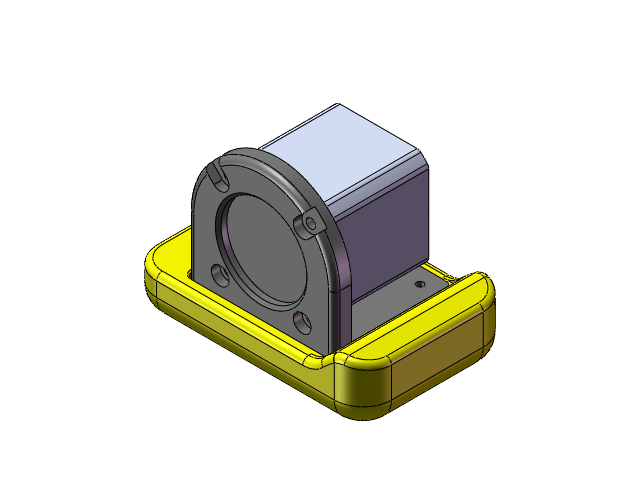
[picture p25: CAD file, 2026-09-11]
hardware/solidworks/Right_ankle.SLDASM
Right_feet
Motor_HTDW3532

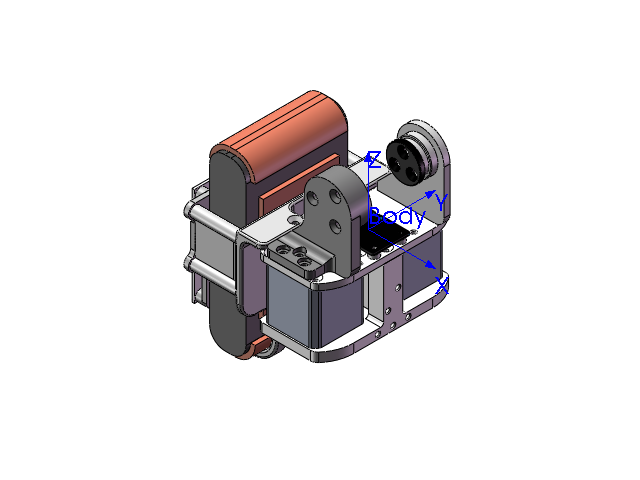
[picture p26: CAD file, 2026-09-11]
hardware/solidworks/Body.SLDASM
Body_Frame
IMU_YB-MRA02
Battery_6s18650_24V
Control_Borad_AT32
Motor_HTDW3532 x 2

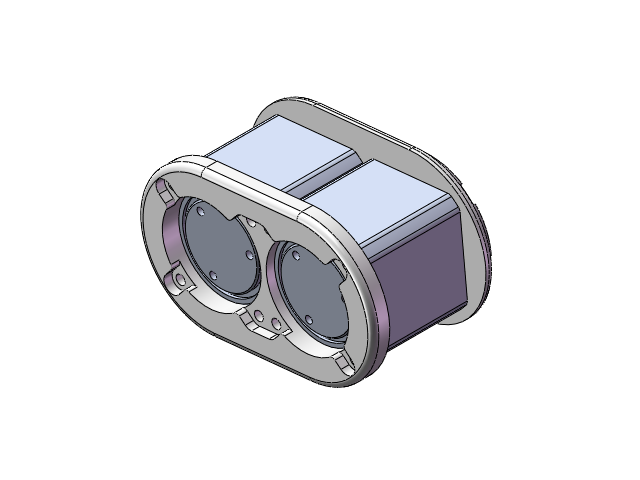
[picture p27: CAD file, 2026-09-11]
hardware/solidworks/Left_hip_pitch.SLDASM
Motor_HTDW3532 x 2
WMD1007
WMD1008

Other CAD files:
hardware/solidworks/Left_hip_yaw.SLDASM
hardware/solidworks/Rightt_hip_pitch.SLDASM
hardware/solidworks/Neck_pitch.SLDASM
hardware/solidworks/Head_roll.SLDASM
hardware/fixtures/standing-zero/step/P02_Head_cradle.step
hardware/fixtures/standing-zero/stl/P01_Main_frame.stl
hardware/fixtures/standing-zero/stl/P02_Head_cradle.stl
hardware/fixtures/standing-zero/stl/P03_Head_keeper_mouth.stl
hardware/fixtures/standing-zero/stl/P04_Body_bridge.stl
hardware/printable/wamoduck-a1mini-standing/Wamoduck_Standing_160mm.stl
hardware/solidworks/Battery_6s18650_24V.SLDPRT
hardware/solidworks/Bearing_20_27_4.SLDPRT
hardware/solidworks/Body_Frame.SLDPRT
hardware/solidworks/Control_Borad_AT32.SLDPRT
hardware/solidworks/Head.SLDPRT
hardware/solidworks/Head_pitch.SLDPRT
hardware/solidworks/IMU_YB-MRA02.SLDPRT
hardware/solidworks/Left_feet.SLDPRT
hardware/solidworks/Left_hip_roll.SLDPRT
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

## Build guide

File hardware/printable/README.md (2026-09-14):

# Printable releases / 可打印发布

This directory contains print-oriented derivatives with an explicit scope, printer target, units, and validation record. Files under [`hardware/step`](../step/) and [`models/wmduck/meshes`](../../models/wmduck/meshes/) are reference geometry and simulation assets; their presence does not make them print-ready robot parts.

本目录收录明确注明用途、目标打印机、单位与验证记录的打印衍生文件。[`hardware/step`](../step/) 与 [`models/wmduck/meshes`](../../models/wmduck/meshes/) 分别是参考几何和仿真资产，不能因文件存在就视为可直接打印的机器人零件。

| Package / 包 | Output / 输出 | Target / 目标 | Status / 状态 |
| --- | --- | --- | --- |
| [Wamoduck A1 mini standing display](wamoduck-a1mini-standing/README.md) / [Wamoduck A1 mini 站立摆件](wamoduck-a1mini-standing/README_打印说明.md) | One fixed 160 mm model / 160 mm 一体固定模型 | A1 mini, PLA, 0.4 mm nozzle, 0.16 mm layers, tree supports / A1 mini、PLA、0.4 mm 喷嘴、0.16 mm 层高、树状支撑 | Geometry and digital slicing verified; physical print not tested / 已完成几何与数字切片检查，尚未实物试打 |

The standing display is decorative and nonfunctional. All joints are fused and cannot move. It is not a replacement for the robot's structural parts, motors, bearings, electronics, or assembly documentation.

站立模型是非功能性展示摆件，所有关节均已融合且不可运动；它不能替代机器人的结构零件、电机、轴承、电子部件或装配资料。

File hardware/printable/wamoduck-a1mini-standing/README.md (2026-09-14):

# Wamoduck standing display for Bambu Lab A1 mini

[中文打印说明](README_打印说明.md) · [Printable releases index](../README.md)

This package produces a **fixed, nonfunctional 160 mm display model** from the Wamoduck URDF at the saved q=0 standing pose. All 15 articulated axes are fused with hidden reinforcement pins; the joints cannot move. Thin surfaces and assembly gaps are consolidated for display printing, so this model is not a manufacturing export or a substitute for functional robot structure.

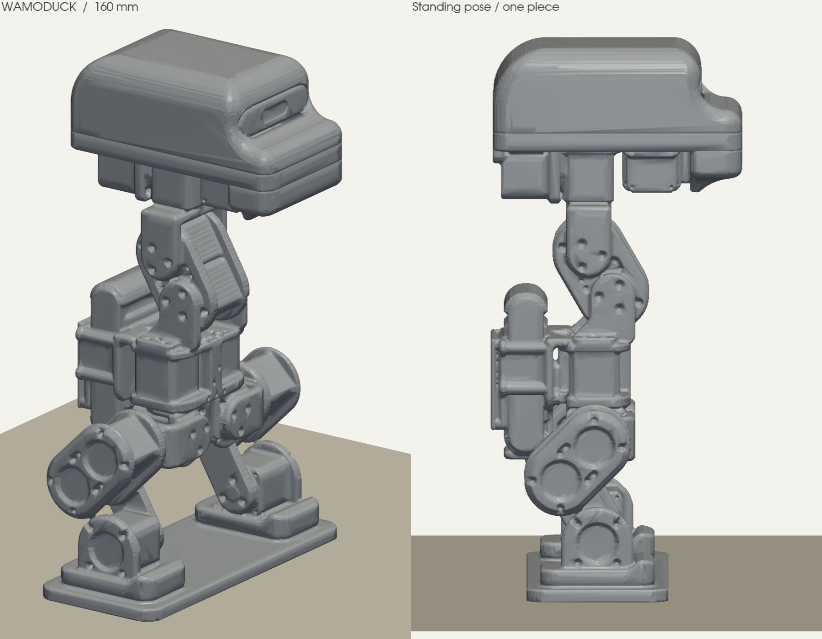
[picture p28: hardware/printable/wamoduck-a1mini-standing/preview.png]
Standing model preview


## Download and print

Open [Wamoduck_A1mini_PLA_160mm.3mf](Wamoduck_A1mini_PLA_160mm.3mf) as a project in Bambu Studio. It contains the model, generated toolpath, and the validated A1 mini settings. The geometry-only [Wamoduck_Standing_160mm.stl](Wamoduck_Standing_160mm.stl) is available for users who need to reslice. [Wamoduck_Standing_160mm.3mf](Wamoduck_Standing_160mm.3mf) is the geometry export; use the A1 mini project above for the saved print configuration.

The validated digital slice uses:

- Bambu Lab A1 mini with a 0.4 mm nozzle;
- one spool of Generic PLA, no AMS or colour changes;
- 0.16 mm layers and a 0.20 mm first layer;
- three walls and 15% gyroid infill;
- automatic tree supports with three top interface layers;
- an 8 mm outer brim on a Textured PEI Plate.

Bambu Studio 02.08.02.60 completed the slice without a reported warning. Its estimate is **11 h 56 min 37 s** and **150.26 g PLA**, including supports, for 1,000 layers. These are slicer estimates. A physical print has not been completed or tested.

The final model is approximately **73.86 × 97.58 × 160.00 mm**, including its integral base. Keep it at 100% import scale to retain the validated dimensions and reinforced thicknesses. Preserve the standing orientation and tree supports around the head, beak and body overhangs.

## Validation and reproducibility

[geometry_validation.json](geometry_validation.json) records the final STL hash, dimensions, triangle count, one-shell/watertight checks, outward winding, positive volume, bottom cap, and source URDF hash. [slicing_validation.json](slicing_validation.json) records the public slicer result, configuration hashes, embedded settings, archive hash, footprint, support statistics, material estimate, and time estimate.

The geometry can be rebuilt from [source/build_model.py](source/build_model.py) using the pinned packages in [source/requirements.txt](source/requirements.txt):

```powershell
python -m pip install -r source/requirements.txt
python source/build_model.py build
python source/build_model.py render
```

The script depends on the repository's URDF and source meshes at their existing relative paths. It omits the zero-thickness IMU sheet, scales the source pose, voxel-unites the visible geometry, adds reinforcement, repairs the result into one shell, and exports millimetre-scale output. Rebuilding the STL does not update the saved sliced project automatically; rerun the documented [offline slicing workflow](slicing/README.md) after any geometry change.

Digital validation proves that the checked geometry is a closed single shell and that Bambu Studio generated a toolpath with the recorded settings. It does not prove surface quality, support removability, strength, dimensional accuracy, printer calibration, or a successful physical print.

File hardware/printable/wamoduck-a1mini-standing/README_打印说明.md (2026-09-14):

# Wamoduck 默认站立 · A1 mini 单色打印版

优先用 Bambu Studio 打开 **Wamoduck_A1mini_PLA_160mm.3mf**。该文件包含一体模型、A1 mini 打印配置和已生成的支撑/切片；也提供 **Wamoduck_Standing_160mm.stl** 供自行设置。

## 模型

- 外形尺寸：前后 **73.86 mm**、左右 **97.58 mm**、总高 **160.00 mm**，包含约 3.5 mm 厚的一体底座。
- 姿态：仓库 `models/wmduck/wmduck.urdf` 的全部 15 个活动关节取 `q=0`，与当前 CAD 默认站立姿态一致。
- 保留头部、眼部凹槽、鸭嘴、机身、电机外形、倾斜颈部及弯曲双腿。
- 所有关节固定并合成一个连续实体；隐藏位置加入约 4.8 mm 直径连接销，薄壁表面适度加厚，合并装配间隙和封闭内腔。双脚连接到薄底座。
- 删除无厚度的内部 IMU 曲面；细小紧固孔、装配缝及内部结构经过简化。嘴缝、外壳轮廓及主要机械特征尽量保留。
- 这是固定摆件，各关节不可活动。保留 100% 导入尺寸可维持当前补强后的厚度。

## 已保存的切片设置

| 项目 | 设置 |
| --- | --- |
| 打印机 | Bambu Lab A1 mini |
| 喷嘴 | 0.4 mm |
| 耗材 | 单卷 Generic PLA，任意单色，不需要 AMS |
| 打印板 | Textured PEI Plate / 纹理 PEI 板 |
| 层高 | 0.16 mm，首层 0.20 mm |
| 墙数 | 3 |
| 填充 | 15% Gyroid / 螺旋体 |
| 支撑 | 自动树状支撑，与模型同一种 PLA |
| 支撑接触 | 顶部 Z 间距 0.20 mm，接口 3 层 |
| 裙边 | 外侧 8 mm |
| 喷嘴 / 热床 | 220°C / 65°C（Generic PLA 预设） |

底座朝下，按保存朝向放在打印板中央。头部下方、鸭嘴和机身有悬垂，**保留树状支撑**。打印后先拆外围支撑，再小心处理颈部、腿部和鸭嘴附近的接触点。

本次 Bambu Studio 02.08.02.60 实际切片：**1000 层，约 11 小时 57 分钟，PLA 约 150.26 g（含支撑等切片用料），0 次换色**，未返回切片警告。模型、支撑和裙边的首层整体占用约 **96.47 × 116.92 mm**，距打印板边缘至少约 31.5 mm。时间和用料为切片估算，实打会随机器与耗材有所变化。

预览颜色仅代表单个耗材槽；实际颜色取决于装入的线材。若使用其他 PLA、喷嘴或打印板，在 Bambu Studio 中选择对应预设后重新切片。

## 检查范围

已从最终二进制 STL 重新读取并检查：单一连通实体、封闭网格、朝外法线、正体积、零退化三角形，以及平整向下的底面。源姿态包络已与仓库验证记录交叉核对。具体数值、文件哈希和独立复核见 JSON 报告。

Bambu Studio 的切片验证仅表示成功生成该配置下的打印路径；尚未进行实物试打。

## 重新生成

`source/build_model.py` 是几何生成脚本，`source/requirements.txt` 固定所需 Python 包。脚本需要保留本文件夹与仓库的相对位置，并依赖原始 URDF 及配套 STL。

```powershell
python -m pip install -r source/requirements.txt
python source/build_model.py build
python source/build_model.py render
```

`slicing/` 保存本次使用的拓竹官方预设展开副本和离线切片脚本；重新生成 STL 后须重新切片，已保存的 3MF 切片不会自动更新。

A1 mini 的官方成型范围为 180 × 180 × 180 mm：[拓竹官方规格](https://asia.store.bambulab.com/en/products/a1-mini)。

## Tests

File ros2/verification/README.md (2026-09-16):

# Verification evidence

Everything in this directory was produced by the commands listed below, on the machine and
versions stated. Nothing here is a description of intent: each file is the captured output of
a run, and the claims in [`../README.md`](../README.md) point back to these files.

If you want to re-run it, the scripts are the only thing you need — see
[Reproducing this](#reproducing-this).

## Environment actually used

| Item | Value |
| --- | --- |
| Host | Windows 11, WSL2 |
| Guest | Ubuntu 24.04 LTS (noble), `x86_64`, kernel `6.18.33.2-microsoft-standard-WSL2` |
| CPU / RAM | 20 cores / 19 GB |
| ROS 2 | **Jazzy**, `/opt/ros/jazzy`, `ros-jazzy-desktop 0.11.0-1noble.20260616.084553` |
| RViz | `ros-jazzy-rviz2 14.1.23-1noble.20260905.070259` |
| robot_state_publisher | `3.3.4-1noble.20260903.022201` |
| colcon | `python3-colcon-common-extensions 0.3.0-100` (colcon-core `0.21.2`) |
| pytest | `7.4.4-1` |
| liburdfdom-tools | `4.0.0-0ubuntu1` |
| Renderer | Mesa **llvmpipe** (`LLVM 20.1.2, 256 bits`), OpenGL 4.5 — **software, no GPU** |
| Build tree | `~/ws_wamoduck` (WSL-native), packages symlinked from `ros2/*` |

**This is x86_64 Ubuntu in WSL2. It is not the RDK X5, and it is not ARM64.** See
[Not covered](#not-covered).

## Files

| File | What it is | What it proves |
| --- | --- | --- |
| `colcon_build_log.txt` | full `colcon build` output | all three packages configure, build and install; the generated URDF manifest is printed |
| `static_verification_log.txt` | `check_urdf` on both URDFs, the geometric verifier, `colcon test`, and `pytest` | the description parses, its geometry matches the published record, and the 87 unit tests pass |
| `runtime_verification_log.txt` | nodes, topic echoes, rate measurement, RViz log, screenshot analysis | `robot_state_publisher` + `gait_player` publish a legal `JointState` stream at 50 Hz and RViz renders it |
| `description_check.json` | machine-readable report from `tools/verify_description.py` | per-check pass/fail, computed bounds, deviations, mesh triangle counts |
| `description_check_canonical_urdf.json` | the same report for `models/wmduck/wmduck.urdf` | the canonical URDF fails **exactly one** check — the working-directory one — which is why the build rewrites mesh paths, and proves the rewrite changes nothing else |
| `rviz_gait_xvfb.png` | RViz screenshot, headless Xvfb + llvmpipe | the description renders: 1400×900, 2346 distinct colours, meshes shaded, grid and TF visible |
| `rviz_gait_wslg.png` | RViz screenshot, WSLg (`:0`) | the same under WSLg — see the note on capture below |

## Key observed results

### Build

```
wamoduck_description  src/wamoduck_description  (ros.ament_cmake)
wamoduck_msgs         src/wamoduck_msgs         (ros.ament_cmake)
wamoduck_ros2         src/wamoduck_ros2         (ros.ament_python)
...
Summary: 3 packages finished [21.6s]
colcon build exit code: 0
```

`(ros.ament_python)` is load-bearing. When it reads `(python)` instead, `colcon build` still
succeeds but no ROS environment is generated for the prefix, so `ros2 launch` can never find
the package. That happened during development (an unescaped `<` in `package.xml`) and is now
covered by `test_package_manifests.py`.

The generated URDF manifest cross-checks the source model:

```
source_urdf_sha256            fd39cb49985354e76bc1e15745bf58e5824461246d492f439db77d5e2c1dd5d1
mesh_references_rewritten     79
unique_meshes_referenced      20
links                         17
movable_joints                15   (URDF document order, including `mouth`)
fixed_joints                  1    (imu_fixed)
structural_equality_vs_source true
```

That source SHA-256 is **identical to `urdf_sha256` in `models/wmduck/validation.json`**, so
the description installed here was built from exactly the URDF the published validation record
covers.

### URDF parsing and geometry

`check_urdf` succeeds on both the canonical and the generated URDF, reporting the same tree:
root `base_link` with children `imu_link`, `left_hip_yaw_link`, `neck_pitch_link`,
`right_hip_yaw_link`, and 16 joints total.

`tools/verify_description.py` then goes past parsing:

```
[PASS] tree_has_exactly_one_root                  roots=['base_link']
[PASS] every_link_is_connected                    16 child links for 17 links
[PASS] no_structural_problems
[PASS] forward_kinematics_reaches_every_link      0 links unreachable
[PASS] mesh_references_were_found_at_all          79 mesh tags under <visual>/<collision>
[PASS] all_mesh_references_resolve                0 unresolved
[PASS] no_mesh_reference_needs_the_rviz_cwd       0 references depend on the working directory
[PASS] every_referenced_mesh_parses_as_binary_stl 20 distinct mesh files
[PASS] zero_pose_bounds_match_the_published_record best variant 'all', deviation 3.140e-09 m
[PASS] triangle_count_matches_the_published_record 237802 triangles, published 237802
[PASS] link_and_joint_counts_match_the_published_record 17 links / 16 joints
[PASS] root_link_matches_the_published_record     ['base_link'] vs base_link
[PASS] left_right_link_frames_are_mirror_symmetric worst deviation 0.000e+00 m over 5 pairs
RESULT: ALL CHECKS PASSED
```

The bounds check is the one that matters for "no obvious misalignment". Forward kinematics is
computed from the URDF alone, every mesh vertex is transformed, and the resulting axis-aligned
box is compared against the published record:

```
published : [-0.08340850082323419, -0.1106025029906681, -0.17761809544517723]
            [-0.08340850082323419 ...]
          .. [0.09809900589255854, 0.11060250303302659, 0.21321191008871637]
computed  : [-0.08340850082323417, -0.11060250211000443, -0.17761809473751067]
          .. [0.09809900275250455, 0.11060250211000443, 0.21321190877487214]
size        published [0.18150750671579274, 0.2212050060236947, 0.3908300055338936]
            computed  [0.18150750357573872, 0.22120500422000886, 0.39083000351238284]
```

The residual is **3.14e-9 m (3.1 nanometres)**. It is float32 rounding, not geometry
disagreement: the STL vertex coordinates are float32, whose epsilon for coordinates of order
0.2 m is ~2.4e-8 m, so an independent double-precision reader cannot reproduce the published
figures bit-for-bit. The tolerance is set to 1e-6 m — three orders of magnitude above that
residual and at least three below any real error (a wrong joint origin, a wrong `rpy`, a wrong
mesh or a wrong scale all move this box by millimetres at minimum). The exact residual is
always recorded in the JSON, so the number can be judged rather than trusted.

Running the same verifier on the **canonical** URDF produces identical geometry results and
fails exactly one check:

```
[FAIL] no_mesh_reference_needs_the_rviz_cwd
       79 references would resolve only from a lucky working directory (RViz launched from /)
RESULT: FAILED  (only this check)
```

That is the defect the build-time rewrite fixes, demonstrated rather than asserted.

### Unit tests

```
build/wamoduck_ros2/pytest.xml: 78 tests, 0 errors, 0 failures, 0 skipped
```

plus the 9 tests in `test_package_manifests.py`, for **87 tests** total, passing both through `colcon test`
and through `python3 -m pytest` directly. What they cover:

* **CRC16-CCITT-FALSE pinned to a published vector** (`"123456789"` → `0x29B1`). A wrong CRC
  variant fails only on the wire and is indistinguishable from a noisy cable.
* **The exact CMD byte layout**, against a byte string assembled by hand in the test (the head
  as literal bytes, the arrays via a format string spelled out in the test rather than reused
  from the module), so a wire-format change must be made in two places.
* Frame sizes: 46 / 38 / 38 / 30 / 10 / 6 bytes; every payload ≤ 64 B for CAN-FD; the 106 B
  uplink round and its 23 % share of a 921600 8N1 UART.
* Round trips with quantisation bounds; **int16 saturation clamps and never wraps**
  (`+99 rad → +32.767`, not `-12`); rejected bad lengths; corrupted frames counted and the
  following good frame preserved; partial frames buffered; noise resynchronised.
* Observation layout position by position; the 48-wide stand layout equal to the 51-wide walk
  layout truncated; **the observation is not normalised**; command clamping to the trained
  ranges.
* `action_to_joint` pinned as the identity, and spelled out by joint name, so a swapped leg
  fails loudly. The action-order adjudication of 2026-09-16 settled that the policy output is
  in joint-tree order, not MJCF `<actuator>` order; the test also names the actuator-order
  permutation it replaced, so reintroducing it fails with a readable message.
* The URDF is read for movable joints, and the test asserts the URDF's document order
  **differs** from the contract order — if someone "tidies" one into the other, the suite fails
  instead of silently re-wiring a joint.
* The gait CSV reader: rebasing, non-uniform timestamps via the median, ragged rows, missing
  columns, and name-based matching with warnings rather than silent drops.
* Both real reference tracks (`100 samples @ 50 Hz`, `1040 samples @ 10 Hz`, 15 joints each).

### Runtime

`robot_state_publisher` + `gait_player`, started through the real launch file:

```
[gait_player]: CSV            : .../share/wamoduck_ros2/data/gait_cycle_2s_50Hz.csv
[gait_player]:                  100 samples, 1.980 s, 50.000 Hz nominal, uniform_dt=True
[gait_player]: URDF           : .../share/wamoduck_description/urdf/wmduck.urdf
[gait_player]:                  15 movable joints in URDF document order: left_hip_yaw,
                 right_hip_yaw, left_hip_roll, right_hip_roll, left_hip_pitch,
                 right_hip_pitch, left_knee, right_knee, left_ankle, right_ankle, neck_pitch,
                 head_pitch, head_yaw, head_roll, mouth
[gait_player]: publishing     : 15 CSV-driven joints in URDF order, timer 50.0 Hz
[gait_player]: base TF        : world -> base_link from base_x/y/z + base_roll_rad
[gait_player]: contract check : URDF document order == contract joint_order ? False
```

`ros2 topic echo /joint_states --once` produces a complete, legal message: 15 names, 15
positions, 15 velocities and 15 efforts, with the names in URDF document order and the values
non-zero (so something is genuinely animating) and finite:

```
name: [left_hip_yaw, right_hip_yaw, left_hip_roll, right_hip_roll, left_hip_pitch,
       right_hip_pitch, left_knee, right_knee, left_ankle, right_ankle, neck_pitch,
       head_pitch, head_yaw, head_roll, mouth]
position: [-0.045697, -0.279275, -0.017825, -0.006765, 0.126214, 0.279829, -0.324853,
           -0.300574, 0.197759, 0.018573, 0.0, 0.0, 0.0, 0.0, 0.0]
```

The head and mouth joints are exactly `0.0` because those columns are zero throughout the
reference CSVs — not because they failed to publish.

`ros2 topic echo /tf --once` shows the base trajectory:

```
frame_id: world
child_frame_id: base_link
translation: {x: 0.039, y: 0.0, z: 0.169618}
rotation:    {x: 0.0, y: 0.0, z: 0.0, w: 1.0}
```

Those come from the CSV's `base_x` / `base_y` / `base_z` / `base_roll_rad`; the CSV carries no
pitch and no yaw, so none is invented.

Rate, measured three independent ways:

| Method | Result |
| --- | --- |
| `ros2 topic hz /joint_states` | `average rate: 49.998` / `49.999`, `min: 0.018s max: 0.022s std dev: 0.00026s` |
| `gait_player` self-report | `published 2199 messages, achieved 50.00 Hz (target 50.00 Hz)` |
| independent subscriber | `observed rate : 50.001 Hz` over 202 received samples |

The subscriber also confirms `names == URDF document order : True`, widths 15/15/15,
`all positions zero : False`, `all positions finite : True`, `all samples stamped : True`.

Read the subscriber row carefully: it reports **202** samples in a 6-second window, which is
not `50 x 6`. That is the intended behaviour, not a shortfall. The subscription uses
`KEEP_LAST(1)` on purpose (`docs/16` §6.5 point 1): a consumer slower than the publisher must
drop stale samples rather than queue them, because a queued stale observation is what makes a
policy appear "sluggish and oscillating". The Python subscriber below only drains when it is
scheduled, so it deliberately sees a subset — and the subset it does see arrives at 50.001 Hz,
measured between its own first and last received message. `ros2 topic hz`, which is written in
C++, is the better rate measurement of the two.

### RViz

RViz was started twice from the same launch file.

**Headless (Xvfb `:99` + llvmpipe software GL, `QT_QPA_PLATFORM=xcb`).** This is the primary
screenshot evidence, and it is reproducible without a GPU or a display:

```
Xvfb :99 -> OpenGL renderer string: llvmpipe (LLVM 20.1.2, 256 bits)
            OpenGL version string: 4.5 (Compatibility Profile) Mesa 25.2.8
RViz window present after ~5 s
0x200106 ".../rviz/wamoduck_world.rviz - RViz": ("rviz2" "rviz2")  1400x900+0+0
```

The window title confirms RViz loaded the config the launch file selected. The PNG is
1400×900 with 2346 distinct colours: background `#303030` (the configured
`Background Color: 48;48;48`), a large band of shaded grey mesh surfaces, and the grid. A blank
or failed render would be a single colour.

The image shows the assembled biped standing on the 1 m grid, mid-gait: legs posed by the
reference track, the two feet staggered, the head and body above. The joint frames are
where the URDF puts them, which is the visual counterpart of the bounds check above.

**WSLg (`DISPLAY=:0`).** RViz starts and creates its window under WSLg (`Weston WM` present,
`fatal-pattern lines: 0`), and a 1400×900 capture of the RViz client window succeeds
(`unique_colours=2460`).

> **Capture caveat.** Reading back WSLg's **root** window with `import`/`xwd` fails
> (`Resource temporarily unavailable`) — WSLg's root window is not a capturable X pixmap. The
> WSLg image is therefore taken from the RViz **client window id** (resolved from
> `xwininfo -root -tree`). It is a screenshot of the same render, but it is captured by a
> different mechanism than the Xvfb one, so the Xvfb image is the one to rely on if the two
> ever disagree.

## Not covered

Stated plainly, because these are the places where "verified" could be overstated:

* **ARM64 / RDK X5 — not verified at all.** Every number above is x86_64 Ubuntu 24.04 under
  WSL2. Nothing was built or run on the X5's ARM64 userspace. The packages are pure Python
  plus one message interface, so the port is *expected* to be uneventful; that is a
  prediction, not a result.
* **Hardware — never touched.** No serial port, no CAN bus, no AT32, no IMU, no motors.
  `bridge_stub`'s `serial` transport has never been opened. Its `can` transport is not
  implemented and raises rather than starting a bridge that silently moves nothing.
* **`policy_node` — skeleton.** No ONNX was loaded, no inference ran, no output was compared
  against a MuJoCo rollout. `onnxruntime` is not installed. The observation assembly, the
  command clamp and the action permutation *are* implemented and unit-tested.
* **No dynamics anywhere.** Stage 2 renders a kinematic tree. RViz integrates nothing,
  collides nothing and applies no gravity. The reference gait is a quasi-static IK plan, not
  hardware data and not a trained policy. **A gait that looks right on screen proves nothing
  about balance.**
* **Gazebo and MoveIt — not started.** `ros-jazzy-ros-gz` is not a dependency of anything here.
* **`wmduck_safety` is not written.** The cerebellum-side protection layer (200 ms HOLD,
  1000 ms OFF, 0.35 rad per frame, limit clamping) is specified in the protocol and lives in
  the firmware. The host deliberately does not duplicate it: two watchdogs with different
  timeouts are worse than one.
* **Foot clearance during the gait was not computed.** Two raw numbers that invite a wrong
  conclusion, so they are given with their scope: the URDF's zero-pose lowest point is
  0.17762 m below `base_link` (`validation.json`), the 2 s cycle's `base_z` is ≈0.16962 m and
  the walk track's is ≈0.17759 m. Read at the *CAD standing pose* that would put the soles
  ~8 mm below `z = 0` for the cycle and ~0 for the walk track. Whether the actual gait poses
  keep the feet above the floor was **not** evaluated; that would require FK over the track,
  and it is a kinematic statement about the plan either way, not a contact or dynamics result.

### Benign warnings you will see

* `[kdl_parser]: The root link base_link has an inertia specified in the URDF, but KDL does not
  support a root link with an inertia.` — `base_link` carries an inertia because the model has
  a real mass distribution. KDL ignores it for TF purposes. It does not affect the rendered
  link frames.
* `RViz: Stereo is NOT SUPPORTED` — expected under llvmpipe and on any non-stereo display.

## Reproducing this

The run scripts live outside the repository, in the WSL guest. To reproduce, from a full clone:

```bash
# 1. workspace
mkdir -p ~/ws_wamoduck/src && cd ~/ws_wamoduck
for p in wamoduck_msgs wamoduck_description wamoduck_ros2; do
  ln -sfn /path/to/Wamoduck/ros2/$p src/$p
done
source /opt/ros/jazzy/setup.bash

# 2. build
colcon build 2>&1 | tee colcon_build_log.txt

# 3. static: parse, geometry, unit tests
check_urdf /path/to/Wamoduck/models/wmduck/wmduck.urdf
check_urdf install/wamoduck_description/share/wamoduck_description/urdf/wmduck.urdf
source install/setup.bash
python3 /path/to/Wamoduck/ros2/tools/verify_description.py \
  --urdf install/wamoduck_description/share/wamoduck_description/urdf/wmduck.urdf \
  --meshes install/wamoduck_description/share/wamoduck_description/meshes \
  --validation /path/to/Wamoduck/models/wmduck/validation.json \
  --rviz-cwd / \
  --report description_check.json
colcon test && colcon test-result --all --verbose
python3 -m pytest /path/to/Wamoduck/ros2/wamoduck_ros2/test -q

# 4. runtime (no display needed for the first part)
ros2 launch wamoduck_ros2 gait_display.launch.py rviz:=false loop:=true &
ros2 topic echo /joint_states --once
ros2 topic echo /tf --once
timeout 12 ros2 topic hz /joint_states

# 5. RViz screenshot, headless, no GPU
Xvfb :99 -screen 0 1400x900x24 &
DISPLAY=:99 LIBGL_ALWAYS_SOFTWARE=1 GALLIUM_DRIVER=llvmpipe QT_QPA_PLATFORM=xcb \
  ros2 launch wamoduck_ros2 gait_display.launch.py loop:=true &
sleep 35
DISPLAY=:99 import -window root rviz_gait_xvfb.png
identify -format '%wx%h unique_colours=%k\n' rviz_gait_xvfb.png
```

Notes worth knowing before you re-run it:

* `verify_description.py` needs `numpy` (it ships with ROS 2) and no display.
* Editing an `.rviz` file requires a **rebuild** for the change to reach `share/`, because the
  configs are copied at install time. This bit during development: the first screenshots used
  the old camera because the install tree still held the previous file. Use
  `colcon build --symlink-install` to avoid it.
* `--loop` and `--no-loop` are stripped from `argv` before `rclpy.init`, so they are not ROS
  arguments; `--ros-args -p loop:=true` is equivalent.
* Do not pipe a long `colcon build` into `Select-Object -First N` (PowerShell) or anything that
  closes the pipe early — it terminates the build mid-install and leaves a half-populated
  `install/`. Redirect to a file and read the file instead.

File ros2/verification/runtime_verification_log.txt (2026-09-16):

########################################################################
# 1. packages and entry points
########################################################################
$ ros2 pkg list | grep wamoduck
wamoduck_description
wamoduck_msgs
wamoduck_ros2

$ ros2 pkg executables wamoduck_ros2
wamoduck_ros2 bridge_stub
wamoduck_ros2 gait_player
wamoduck_ros2 policy_node

########################################################################
# 2. robot_state_publisher + gait_player (via the real launch file)
########################################################################
$ ros2 launch wamoduck_ros2 gait_display.launch.py rviz:=false loop:=true csv_path:=<gait_cycle_2s_50Hz.csv>
launch pid 1479
/joint_states appeared after ~0 s

--- launch log (filtered: gait_player and robot_state_publisher) ---
  [INFO] [robot_state_publisher-1]: process started with pid [1487]
  [INFO] [gait_player-2]: process started with pid [1488]
  [robot_state_publisher-1] [WARN] [1789545435.754410433] [kdl_parser]: The root link base_link has an inertia specified in the URDF, but KDL does not support a root link with an inertia.  As a workaround, you can add an extra dummy link to your URDF.
  [robot_state_publisher-1] [INFO] [1789545435.754562611] [robot_state_publisher]: Robot initialized
  [gait_player-2] [INFO] [1789545436.213821332] [gait_player]: CSV            : /home/sim/ws_wamoduck/install/wamoduck_ros2/share/wamoduck_ros2/data/gait_cycle_2s_50Hz.csv
  [gait_player-2] [INFO] [1789545436.214189081] [gait_player]:                  100 samples, 1.980 s, 50.000 Hz nominal, uniform_dt=True
  [gait_player-2] [INFO] [1789545436.214390869] [gait_player]: URDF           : /home/sim/ws_wamoduck/install/wamoduck_description/share/wamoduck_description/urdf/wmduck.urdf
  [gait_player-2] [INFO] [1789545436.214631824] [gait_player]:                  15 movable joints in URDF document order: left_hip_yaw, right_hip_yaw, left_hip_roll, right_hip_roll, left_hip_pitch, right_hip_pitch, left_knee, right_knee, left_ankle, right_ankle, neck_pitch, head_pitch, head_yaw, head_roll, mouth
  [gait_player-2] [INFO] [1789545436.214934564] [gait_player]: publishing     : 15 CSV-driven joints in URDF order, timer 50.0 Hz
  [gait_player-2] [INFO] [1789545436.215180673] [gait_player]: base TF        : world -> base_link from base_x/y/z + base_roll_rad
  [gait_player-2] [INFO] [1789545436.215431739] [gait_player]: contract check : URDF document order == contract joint_order ? False (false is expected and fine; see model_contract.py)
  [gait_player-2] [INFO] [1789545439.203221263] [gait_player]: restarting the 1.980 s track (loop enabled)

--- ros2 node list ---
/gait_player
/robot_state_publisher

--- ros2 topic list ---
/joint_states
/parameter_events
/robot_description
/rosout
/tf
/tf_static

--- ros2 topic info /joint_states -v (first 25 lines) ---
Type: sensor_msgs/msg/JointState

Publisher count: 1

Node name: gait_player
Node namespace: /
Topic type: sensor_msgs/msg/JointState
Topic type hash: RIHS01_a13ee3a330e346c9d87b5aa18d24e11690752bd33a0350f11c5882bc9179260e
Endpoint type: PUBLISHER
GID: 01.0f.f2.62.d0.05.61.7a.00.00.00.00.00.00.13.03
QoS profile:
  Reliability: RELIABLE
  History (Depth): UNKNOWN
  Durability: VOLATILE
  Lifespan: Infinite
  Deadline: Infinite
  Liveliness: AUTOMATIC
  Liveliness lease duration: Infinite

Subscription count: 1

Node name: robot_state_publisher
Node namespace: /
Topic type: sensor_msgs/msg/JointState
Topic type hash: RIHS01_a13ee3a330e346c9d87b5aa18d24e11690752bd33a0350f11c5882bc9179260e

--- ros2 topic info /tf ---
Type: tf2_msgs/msg/TFMessage
Publisher count: 2
Subscription count: 0

########################################################################
# 3. ros2 topic echo /joint_states --once
########################################################################
header:
  stamp:
    sec: 1789545442
    nanosec: 2792622
  frame_id: base_link
name:
- left_hip_yaw
- right_hip_yaw
- left_hip_roll
- right_hip_roll
- left_hip_pitch
- right_hip_pitch
- left_knee
- right_knee
- left_ankle
- right_ankle
- neck_pitch
- head_pitch
- head_yaw
- head_roll
- mouth
position:
- -0.083999
- -0.245634
- -0.011794
- 0.002143
- 0.088942
- 0.26098
- -0.301914
- -0.298705
- 0.211886
- 0.038051
- 0.0
- 0.0
- 0.0
- -0.0
- 0.0
velocity:
- 0.10859999999999992
- -0.10174999999999966
- -0.01947499999999999
- -0.026124999999999975
- 0.10619999999999995
- 0.0012749999999991924
- -0.07249999999999888
- 0.0847250000000007
- -0.03417500000000015
- -0.09202499999999984
- 0.0
- 0.0
- 0.0
- 0.0
- 0.0
effort:
- 0.392989
- 1.280627
- 0.06378
- 0.002485
- -0.448915
- -1.31181
- 1.478134
- 1.461709
- -1.02382
- -0.148225
- 0.0
- 0.0
- -0.0
- 0.0
- 0.0
---

########################################################################
# 4. ros2 topic echo /tf --once  (world -> base_link from the CSV base columns)
########################################################################
transforms:
- header:
    stamp:
      sec: 1789545443
      nanosec: 122681068
    frame_id: world
  child_frame_id: base_link
  transform:
    translation:
      x: 0.039
      y: 0.0
      z: 0.169618
    rotation:
      x: -0.0
      y: 0.0
      z: 0.0
      w: 1.0
---

########################################################################
# 5. achieved publish rate
########################################################################
$ timeout 12 ros2 topic hz /joint_states
	min: 0.018s max: 0.022s std dev: 0.00026s window: 404
average rate: 49.998
	min: 0.018s max: 0.022s std dev: 0.00026s window: 455
average rate: 49.999
	min: 0.018s max: 0.022s std dev: 0.00026s window: 506

--- gait_player self-reported rate ---
  [gait_player-2] [INFO] [1789545441.203682072] [gait_player]: published 200 messages, achieved 50.00 Hz (target 50.00 Hz)
  [gait_player-2] [INFO] [1789545446.203532559] [gait_player]: published 450 messages, achieved 50.00 Hz (target 50.00 Hz)
  [gait_player-2] [INFO] [1789545451.203394787] [gait_player]: published 700 messages, achieved 50.00 Hz (target 50.00 Hz)

########################################################################
# 6. independent subscriber check: names, widths, ranges
########################################################################
samples received in 6 s : 202
name count              : 15
names                   : left_hip_yaw, right_hip_yaw, left_hip_roll, right_hip_roll, left_hip_pitch, right_hip_pitch, left_knee, right_knee, left_ankle, right_ankle, neck_pitch, head_pitch, head_yaw, head_roll, mouth
names == URDF document order : True
position width          : 15
velocity width          : 15
effort width            : 15
total published positions in window: 3030
position range over window: [-0.482773, 0.345952] rad
all positions zero      : False   <- must be False, or nothing is animating
all positions finite    : True
observed rate           : 50.001 Hz
all samples stamped     : True
subscriber check exit code: 0

########################################################################
# 7. RViz headless (Xvfb + llvmpipe): the screenshot evidence
########################################################################
Xvfb pid 1770 on :99
$ glxinfo (software renderer check)
  OpenGL vendor string: Mesa
  OpenGL renderer string: llvmpipe (LLVM 20.1.2, 256 bits)
  OpenGL version string: 4.5 (Compatibility Profile) Mesa 25.2.8-0ubuntu0.24.04.2

$ ros2 launch wamoduck_ros2 gait_display.launch.py  (DISPLAY=:99, LIBGL_ALWAYS_SOFTWARE=1, QT_QPA_PLATFORM=xcb)
rviz launch pid 1831
RViz window present after ~5 s
--- rviz log (tail) ---
  [rviz2-2] [INFO] [1789545465.841261574] [rviz2]: Stereo is NOT SUPPORTED
  [rviz2-2] [INFO] [1789545465.841591246] [rviz2]: OpenGl version: 4.5 (GLSL 4.5)
  [rviz2-2] [INFO] [1789545465.881006998] [rviz2]: Stereo is NOT SUPPORTED
  [gait_player-3] [INFO] [1789545466.094716703] [gait_player]: CSV            : /home/sim/ws_wamoduck/install/wamoduck_ros2/share/wamoduck_ros2/data/gait_cycle_2s_50Hz.csv
  [gait_player-3] [INFO] [1789545466.095166442] [gait_player]:                  100 samples, 1.980 s, 50.000 Hz nominal, uniform_dt=True
  [gait_player-3] [INFO] [1789545466.095373928] [gait_player]: URDF           : /home/sim/ws_wamoduck/install/wamoduck_description/share/wamoduck_description/urdf/wmduck.urdf
  [gait_player-3] [INFO] [1789545466.095579058] [gait_player]:                  15 movable joints in URDF document order: left_hip_yaw, right_hip_yaw, left_hip_roll, right_hip_roll, left_hip_pitch, right_hip_pitch, left_knee, right_knee, left_ankle, right_ankle, neck_pitch, head_pitch, head_yaw, head_roll, mouth
  [gait_player-3] [INFO] [1789545466.095830608] [gait_player]: publishing     : 15 CSV-driven joints in URDF order, timer 50.0 Hz
  [gait_player-3] [INFO] [1789545466.096083137] [gait_player]: base TF        : world -> base_link from base_x/y/z + base_roll_rad
  [gait_player-3] [INFO] [1789545466.096346568] [gait_player]: contract check : URDF document order == contract joint_order ? False (false is expected and fine; see model_contract.py)
  [gait_player-3] [INFO] [1789545469.083057591] [gait_player]: restarting the 1.980 s track (loop enabled)
  [gait_player-3] [INFO] [1789545471.082839490] [gait_player]: restarting the 1.980 s track (loop enabled)
  [gait_player-3] [INFO] [1789545471.083510165] [gait_player]: published 199 messages, achieved 50.00 Hz (target 50.00 Hz)
  [gait_player-3] [INFO] [1789545473.082775169] [gait_player]: restarting the 1.980 s track (loop enabled)
  [gait_player-3] [INFO] [1789545475.063057257] [gait_player]: restarting the 1.980 s track (loop enabled)
  [gait_player-3] [INFO] [1789545476.083512548] [gait_player]: published 449 messages, achieved 50.00 Hz (target 50.00 Hz)
  [gait_player-3] [INFO] [1789545477.062795073] [gait_player]: restarting the 1.980 s track (loop enabled)
  [gait_player-3] [INFO] [1789545479.042874026] [gait_player]: restarting the 1.980 s track (loop enabled)
  [gait_player-3] [INFO] [1789545481.042867221] [gait_player]: restarting the 1.980 s track (loop enabled)
  [gait_player-3] [INFO] [1789545481.083176766] [gait_player]: published 699 messages, achieved 50.00 Hz (target 50.00 Hz)
  [gait_player-3] [INFO] [1789545483.022850237] [gait_player]: restarting the 1.980 s track (loop enabled)
  [gait_player-3] [INFO] [1789545485.024128054] [gait_player]: restarting the 1.980 s track (loop enabled)
  [gait_player-3] [INFO] [1789545486.083271133] [gait_player]: published 949 messages, achieved 50.00 Hz (target 50.00 Hz)
  [gait_player-3] [INFO] [1789545487.003968806] [gait_player]: restarting the 1.980 s track (loop enabled)
  [gait_player-3] [INFO] [1789545489.003380384] [gait_player]: restarting the 1.980 s track (loop enabled)

--- X windows on :99 ---
  
  xwininfo: Window id: 0x21f (the root window) (has no name)
  
    Root window id: 0x21f (the root window) (has no name)
    Parent window id: 0x0 (none)
       4 children:
       0x200106 "/home/sim/ws_wamoduck/install/wamoduck_description/share/wamoduck_description/rviz/wamoduck_world.rviz - RViz": ("rviz2" "rviz2")  1400x900+0+0  +0+0
       0x400001 (has no name): ()  1x1+0+0  +0+0
       0x200008 "rviz2": ()  1x1+0+0  +0+0
       0x200004 "Qt Selection Owner for rviz2": ()  3x3+0+0  +0+0

--- screenshot: import -display :99 -window root ---
-rwxrwxrwx 1 sim sim 66106 Sep 16 15:58 /mnt/e/Github/Wamoduck/ros2/verification/rviz_gait_xvfb.png
  /mnt/e/Github/Wamoduck/ros2/verification/rviz_gait_xvfb.png PNG 1400x900 1400x900+0+0 8-bit sRGB 66106B 0.000u 0:00.009

--- screenshot content analysis (ImageMagick, no extra dependency) ---
size=1400x900  unique_colours=2346  mean_intensity=0.290257
  most common colours:
           1048492: (47.9572,47.9533,47.965) #303030 srgb(18.8067%,18.8052%,18.8098%)
            148937: (240.144,240.171,240.105) #F0F0F0 srgb(94.1741%,94.1848%,94.1588%)
             38068: (103.786,103.794,109.086) #68686D srgb(40.7004%,40.7034%,42.7787%)
             15410: (124.105,124.163,131.463) #7C7C83 srgb(48.6687%,48.6915%,51.5541%)
              5604: (153.171,154.198,159.198) #999A9F srgb(60.0671%,60.47%,62.4308%)
              2710: (62.5214,47.7588,63.9261) #3F3040 srgb(24.5182%,18.7289%,25.069%)
               407: (39.3152,96.0623,166.716) #2760A7 srgb(15.4177%,37.6715%,65.3788%)
               372: (154.677,139.821,114.996) #9B8C73 srgb(60.6577%,54.8318%,45.0965%)

########################################################################
# 8. RViz on WSLg (DISPLAY=:0) -- the GUI path
########################################################################
DISPLAY=:0 WAYLAND_DISPLAY=wayland-0
--- rviz2 process alive on WSLg? ---
  2135 /opt/ros/jazzy/lib/rviz2/rviz2 -d /home/sim/ws_wamoduck/install/wamoduck_description/share/wamoduck_description/rviz/wamoduck_world.rviz --ros-args -r __node:=rviz2
--- fatal errors in the WSLg log? ---
  fatal-pattern lines: 0
--- X windows on :0 (proves the GUI window was created) ---
  
  xwininfo: Window id: 0x438 (the root window) (has no name)
  
    Root window id: 0x438 (the root window) (has no name)
    Parent window id: 0x0 (none)
       7 children:
       0x20002a (has no name): ()  1476x997+1811+646  +1811+646
       0x800001 (has no name): ()  1x1+0+0  +0+0
       0x600008 "rviz2": ()  1x1+0+0  +0+0
       0x600004 "Qt Selection Owner for rviz2": ()  3x3+0+0  +0+0
       0x200027 "Weston WM": ()  10x10+0+0  +0+0
       0x200002 (has no name): ()  8192x8192+0+0  +0+0
       0x200001 (has no name): ()  10x10+0+0  +0+0
  
--- rviz log tail ---
  [gait_player-3] [INFO] [1789545526.656117401] [gait_player]: restarting the 1.980 s track (loop enabled)
  [gait_player-3] [INFO] [1789545528.636168182] [gait_player]: restarting the 1.980 s track (loop enabled)
  [gait_player-3] [INFO] [1789545528.816588677] [gait_player]: published 1700 messages, achieved 50.00 Hz (target 50.00 Hz)
  [gait_player-3] [INFO] [1789545530.616376124] [gait_player]: restarting the 1.980 s track (loop enabled)
  [gait_player-3] [INFO] [1789545532.616163789] [gait_player]: restarting the 1.980 s track (loop enabled)
  [gait_player-3] [INFO] [1789545533.817449993] [gait_player]: published 1950 messages, achieved 50.00 Hz (target 50.00 Hz)
  [gait_player-3] [INFO] [1789545534.596145930] [gait_player]: restarting the 1.980 s track (loop enabled)
  [gait_player-3] [INFO] [1789545536.576195959] [gait_player]: restarting the 1.980 s track (loop enabled)
  [gait_player-3] [INFO] [1789545538.576102902] [gait_player]: restarting the 1.980 s track (loop enabled)
  [gait_player-3] [INFO] [1789545538.817476821] [gait_player]: published 2200 messages, achieved 50.00 Hz (target 50.00 Hz)
  [gait_player-3] [INFO] [1789545540.556143029] [gait_player]: restarting the 1.980 s track (loop enabled)
  [gait_player-3] [INFO] [1789545542.538133681] [gait_player]: restarting the 1.980 s track (loop enabled)

--- screenshot attempt on :0 ---
WSLg's root window is not a capturable X pixmap; capturing a client window by id instead.
RViz window id on :0: 0x600105
size=1400x900 unique_colours=2460

=== RUNTIME VERIFICATION DONE ===

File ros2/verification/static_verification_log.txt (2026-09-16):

########################################################################
# 1. check_urdf on the CANONICAL urdf (models/wmduck/wmduck.urdf)
########################################################################
$ check_urdf /mnt/e/Github/Wamoduck/models/wmduck/wmduck.urdf
robot name is: wmduck
---------- Successfully Parsed XML ---------------
root Link: base_link has 4 child(ren)
    child(1):  imu_link
    child(2):  left_hip_yaw_link
        child(1):  left_hip_roll_link
            child(1):  left_hip_pitch_link
                child(1):  left_knee_link
                    child(1):  left_ankle_link
    child(3):  neck_pitch_link
        child(1):  head_pitch_link
            child(1):  head_yaw_link
                child(1):  head_roll_link
                    child(1):  mouth_link
    child(4):  right_hip_yaw_link
        child(1):  right_hip_roll_link
            child(1):  right_hip_pitch_link
                child(1):  right_knee_link
                    child(1):  right_ankle_link
check_urdf exit code: 0

########################################################################
# 2. check_urdf on the GENERATED, ROS-installable urdf
########################################################################
$ check_urdf /home/sim/ws_wamoduck/install/wamoduck_description/share/wamoduck_description/urdf/wmduck.urdf
robot name is: wmduck
---------- Successfully Parsed XML ---------------
root Link: base_link has 4 child(ren)
    child(1):  imu_link
    child(2):  left_hip_yaw_link
        child(1):  left_hip_roll_link
            child(1):  left_hip_pitch_link
                child(1):  left_knee_link
                    child(1):  left_ankle_link
    child(3):  neck_pitch_link
        child(1):  head_pitch_link
            child(1):  head_yaw_link
                child(1):  head_roll_link
                    child(1):  mouth_link
    child(4):  right_hip_yaw_link
        child(1):  right_hip_roll_link
            child(1):  right_hip_pitch_link
                child(1):  right_knee_link
                    child(1):  right_ankle_link
check_urdf exit code: 0

########################################################################
# 3. same check via the standalone liburdfdom-tools binary
########################################################################
$ /usr/bin/check_urdf /home/sim/ws_wamoduck/install/wamoduck_description/share/wamoduck_description/urdf/wmduck.urdf   (dpkg: 4.0.0-0ubuntu1)
liburdfdom-tools check_urdf: OK

########################################################################
# 4a. geometry: FK at q=0 vs the published validation record
########################################################################
$ python3 /mnt/e/Github/Wamoduck/ros2/tools/verify_description.py --urdf <installed urdf> \
      --meshes <installed meshes> --validation models/wmduck/validation.json \
      --rviz-cwd /   (a directory that is NOT the package, to prove the URDF
                      does not depend on the working directory)
==============================================================================
description verification: /home/sim/ws_wamoduck/install/wamoduck_description/share/wamoduck_description/urdf/wmduck.urdf
==============================================================================
  [PASS] tree_has_exactly_one_root
          roots=['base_link']
  [PASS] every_link_is_connected
          16 child links for 17 links
  [PASS] no_structural_problems
  [PASS] forward_kinematics_reaches_every_link
          0 links unreachable: []
  [PASS] mesh_references_were_found_at_all
          79 mesh tags under <visual>/<collision>; 0 would make the mesh checks below vacuous
  [PASS] all_mesh_references_resolve
          0 unresolved: []
  [PASS] no_mesh_reference_needs_the_rviz_cwd
          0 references would resolve only from a lucky working directory (RViz launched from /): []
  [PASS] every_referenced_mesh_parses_as_binary_stl
          20 distinct mesh files parsed
  [PASS] zero_pose_bounds_match_the_published_record
          best variant 'all' deviates by 3.140e-09 m (tolerance 1e-06 m); per-variant {'all': 3.140053994599157e-09, 'visual': 3.140053994599157e-09, 'collision': 3.140053994599157e-09}
  [PASS] triangle_count_matches_the_published_record
          URDF references 237802 triangles across 20 unique meshes, published record says 237802
  [PASS] link_and_joint_counts_match_the_published_record
          17 links / 16 joints vs published 17 / 15+1
  [PASS] root_link_matches_the_published_record
          ['base_link'] vs base_link
  [PASS] left_right_link_frames_are_mirror_symmetric
          worst deviation 0.000e+00 m over 5 pairs

  published zero-pose bounds : [-0.08340850082323419, -0.1106025029906681, -0.17761809544517723] .. [0.09809900589255854, 0.11060250303302659, 0.21321191008871637]
  best matching variant      : all (deviation 3.140e-09 m)

  computed bounds [all      ] : [-0.08340850082323417, -0.11060250211000443, -0.17761809473751067] .. [0.09809900275250455, 0.11060250211000443, 0.21321190877487214]
  computed size   [all      ] : [0.18150750357573872, 0.22120500422000886, 0.39083000351238284]
  computed bounds [visual   ] : [-0.08340850082323417, -0.11060250211000443, -0.17761809473751067] .. [0.09809900275250455, 0.11060250211000443, 0.21321190877487214]
  computed size   [visual   ] : [0.18150750357573872, 0.22120500422000886, 0.39083000351238284]
  computed bounds [collision] : [-0.08340850082323417, -0.11060250211000443, -0.17761809473751067] .. [0.09809900275250455, 0.11060250211000443, 0.21321190877487214]
  computed size   [collision] : [0.18150750357573872, 0.22120500422000886, 0.39083000351238284]
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

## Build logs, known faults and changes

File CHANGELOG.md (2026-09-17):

# Changelog / 更新记录

## Unreleased / 尚未发布

### 2026-09-17 — The demo says what the policy does, and which keys work, in the window / 演示窗口里直接说明"这是什么策略、现在哪些键有用"

- **The in-viewer status block is rewritten, after the user reported that the policy names are easy to misread and that a four-line bilingual block came out as garbage.** It leads with the **plain description in both languages** (`[3/5] 坐下与站起 Sit down and stand up`), keeps the **version handle** next to it (`sitstand = sit_stand_v3 · obs 49-D · 平地 flat`) because that is what ties the running file to a checkpoint and a hash, then lists **the keys that actually work for the running policy** — filtered from the same table the terminal uses, so a dead key can never be advertised — and finally **what to try** (`按 m 坐下 → 看躯干是否直立、左右两腿是否对称 → 按 e/z 调高度 → 再按 m 站回`). / **查看器里的状态块重写了。** 起因是用户反馈两点：策略名容易误读，以及四行中英混排的信息块在画面上糊成一片。新版以**白话描述（中英）**打头（`[3/5] 坐下与站起 Sit down and stand up`），紧跟着**版本号**（`sitstand = sit_stand_v3 · obs 49-D · 平地 flat` —— 它是把当前文件对上检查点与哈希的把手），然后是**当前策略真的有效的按键**（从终端同一张键表按策略过滤，所以不可能列出无效键），最后是**建议怎么玩**。
- **Two rendering facts forced the implementation, and both are worth knowing.** MuJoCo's HUD font is bitmap **ASCII**, so Chinese came out as boxes; and `set_texts` draws entries that share a grid position **on top of each other** rather than wrapping, which is what produced the overlapping smear. The block is therefore rendered with Pillow (system CJK font) into an RGB panel and blitted with `viewer.set_images`. **This does not add a dependency**: `mujoco`, `onnxruntime` and `numpy` are still the only required imports, and without Pillow or a CJK font the overlay falls back to English text placed in four *separate* grid cells. Knobs: `--overlay-corner`, `--overlay-width`, `--overlay-scale` (0 = automatic from the window height). / **两个渲染事实决定了实现方式，两点都值得知道。** MuJoCo 的 HUD 字体是**点阵 ASCII**，所以中文会变成方块；而 `set_texts` 里同一格子上的多条文本是**叠在一起**画的、不会换行 —— 这正是那团重叠糊线的来源。因此这块改成用 Pillow（系统中文字体）渲染成 RGB 面板，再用 `viewer.set_images` 贴上去。**这没有增加依赖**：必需的 import 仍然只有 `mujoco`、`onnxruntime`、`numpy`；没有 Pillow 或中文字体时，信息板退回**英文文本**并分散到四个**不同**格子。可调项：`--overlay-corner`、`--overlay-width`、`--overlay-scale`（0 = 按窗口高度自适应）。
- **Two self-inflicted bugs are recorded rather than quietly fixed, because the test set could not see them.** `run_viewer` read `args.overlay_*` although it only receives `demo` (so the demo died with `NameError` the moment the overlay was drawn), and the text fallback passed a one-element list where `set_texts` wants a list of 4-tuples. Both live on the "a window is open" path, which `--check`, `--overlay-preview` and `--cycle-test` never take. The overlay logic now sits in one `OverlayState.apply()` shared by the loop and a new **`--viewer-smoke`** test that opens a real window and walks all five policies through `set_images`/`set_texts`, reporting the panel size and whether it was actually placed. / **我自己引入的两个 bug 如实记录，而不是悄悄修掉 —— 因为原来的测试集根本看不到它们。** `run_viewer` 只收到 `demo`，却读了 `args.overlay_*`（于是**一画出信息板就 `NameError` 崩掉**）；文本兜底那行又传了一个"套了一层的列表"，而 `set_texts` 要的是四元组列表。两个都落在"**开着窗口**"这条路径上，而 `--check`、`--overlay-preview`、`--cycle-test` 都不走它。现在这块逻辑集中在 `OverlayState.apply()`，交互循环与新增的 **`--viewer-smoke`** 共用：后者真开窗口把五个策略都画一遍，逐条报告面板尺寸与"是否真的贴上"。
- **Also added: `--overlay-preview` and `--overlay-png`.** They print the block's rows for all five policies, and write the pixels it would blit, so the layout can be checked before a release without a display — which is exactly how the overlap and the boxes reached a user in the first place. / **另外新增 `--overlay-preview` 与 `--overlay-png`**：把五个策略的信息板按行打印出来，并把**实际会贴上去的那张图**存成 PNG，从而在**没有显示器**的情况下也能检查排版 —— 而当初那团重叠与方块，正是因为没有办法检查才递到用户眼前的。

### 2026-09-16 — The stricter get-up criterion, re-measured at 256 environments / 更严的起身口径在 256 环境下重测

- **The six-axis get-up figure was sample-limited, and the larger run says so.** At **256 environments**, `getup_v20` passes all six axes **206/256 (80.5 %)**, with per-axis rates tilt **239/256**, both feet **221/256**, joint deviation **237/256**, base height **255/256**, head off the ground **253/256**, flat soles **209/256**. At the **64**-environment setting used for the earlier numbers the same criterion read **45/64 (70.3 %)** with the same shape (56/52/58/61/61/46). The per-axis rates are the stable part; the all-six conjunction is limited by how many environments the run sampled, so the 256-environment run is the better estimate. Ranges and means barely move: final tilt **2.65°**, largest joint deviation **10.26°**, head ground reaction **0.00 N**, sole-to-flat **2.61°**. / **六轴那个起身数字受样本量限制，跑大一次就把这件事说清楚了。** 在 **256 环境**下 `getup_v20` 六轴一起过 **206/256（80.5 %）**，逐轴为 倾角 **239/256**、双脚着地 **221/256**、关节偏差 **237/256**、基座高度 **255/256**、头不压地 **253/256**、脚掌平贴 **209/256**。而在先前那些数字用的 **64 环境**设置下，同一条口径读作 **45/64（70.3 %）**，形状相同（56/52/58/61/61/46）。**逐轴比例才是稳定的部分**，六轴的"全部同时成立"受采样环境数限制，因此 256 环境那次是更可信的估计。均值与极值几乎不动：末态倾角 **2.65°**、最大关节偏差 **10.26°**、头链地面反力 **0.00 N**、脚掌离平贴 **2.61°**。
- **The cross-check on the "both feet" axis repeats at the larger sample.** That axis is read through `stand_criteria`, whose contact path this project has flagged as unreliable: it reports **245/256** where the contact sensors report **256/256** (and **60/64** against **64/64** at 64 environments). The axis is biased low in both runs; the two axes added for head clearance and sole flatness do not use that path. / **"双脚着地"那条轴的交叉检验在更大样本上重现。** 它通过 `stand_criteria` 读，而那条接触路径被本项目自己标注为可疑：它给 **245/256**，接触传感器给 **256/256**（64 环境下是 **60/64** 对 **64/64**）。两次运行里这条轴都偏低；新增的"头不压地""脚掌平贴"两条轴不走那条路径。
- **No policy changed.** This is a re-measurement of the policy already published, at four times the environment count; the numbers above are the ones to quote, and the earlier 64-environment figures stay on the page next to them so the two can be compared. / **没有换策略。** 这是对已发布策略在**四倍环境数**下的重新测量；应当引用的是上面这组数字，而先前的 64 环境数字仍留在页面上以便对照。

### 2026-09-16 — A flat-ground control for the rough-terrain row / 越障那一行补上了平地对照

- **The rough-terrain row said "no flat-ground control run was made in the same batch, so the loss cannot be attributed to the terrain alone". A CPU control now separates the two halves of that sentence.** Running the published policy in the bundled runner — CPU MuJoCo, 600 control steps (12 s), `vx = +0.30 m/s`, commanded **3.600 m** — it travelled **+3.458 m (96.1 %)** on a flat floor and **+3.316 m (92.1 %)** over 3 consecutive 1 cm curbs. So in this setup the curbs cost about **4 percentage points**, not 39. That does **not** overturn the **61 %** on the capability board: that figure comes from the development repository's **generated** terrain at difficulty rows 0–5, which is denser and includes step-downs, and it was measured in a different simulator under a different protocol. What it shows is that the loss is specific to that harder terrain rather than the policy being unable to hold speed on uneven ground. Both runs are ours, on CPU, and are labelled as such — they are not a re-measurement of the internal batch. / **越障那一行原本写着"同批没有跑平地对照，所以不能把掉速单独归因给地形"。现在用 CPU 对照把那句话的两半分开了。** 用随仓库的运行器跑公开策略 —— 纯 CPU MuJoCo、600 控制步（12 s）、`vx = +0.30 m/s`、指令 **3.600 m** —— 平地走 **+3.458 m（96.1 %）**，连续 3 个 1 cm 台阶走 **+3.316 m（92.1 %）**。也就是说这套设置下台阶只让它掉约 **4 个百分点**而不是 39。这**不**推翻能力清单上的 **61 %**：那个数字来自研发仓库的**生成式**地形（难度行 0–5，更密且含下台阶），是在另一个仿真器、另一套协议下测的。它说明掉速是**那套更难地形**特有的，而不是"策略遇到不平地面就保不住速度"。两次运行都是我们自己在 CPU 上做的，并已如此标注 —— **不是**对内部那批的重新测量。

### 2026-09-16 — The get-up policy is replaced: it now returns to the nominal stance / 起身策略已替换：现在能站回标称姿态

- **`getup_v20` replaces `getup_v18` as the published get-up policy, and it closes the gap this repository measured on the old one.** Recovering from a random lying pose: standing at the end **64/64**, time to first standing **0.48 s** median (p90 **0.79 s**), final tilt **2.5°**; the strict criterion "back to the saved nominal pose" goes **0/64 → 63/64 (98.4 %)** with the largest joint deviation **52.3° → 10.4°**; and the end-to-end hand-over (shoved over → gets up → back to nominal) is **5/5**, with **5/5** on "did not fall again after standing up" (the old policy was **4/5** there). The new file is [`policies/wamoduck-getup-getup_v20.onnx`](policies/wamoduck-getup-getup_v20.onnx), SHA-256 `29bbebd0d6597a1f425305c90fc29a1b71c79e066a26ae44c20e1fab3a3fbed6`, exported from run `2026-09-16_19-12-01_getup_v20`, checkpoint `model_3999.pt`, verified by `tools/verify_onnx_provenance.py` with a **zero** element-wise difference. / **`getup_v20` 取代 `getup_v18` 成为公开的起身策略，补上了本仓库在旧版上实测到的差距。** 随机躺姿起身：末态站住 **64/64**、首次站起用时中位 **0.48 s**（p90 **0.79 s**）、末态倾角 **2.5°**；严格口径"回到保存的标称姿态" **0/64 → 63/64（98.4 %）**，最大关节偏差 **52.3° → 10.4°**；端到端接力（推倒→起身→站回标称）**5/5**，其中"起身后没有再次摔倒"**5/5**（旧版那一行是 **4/5**）。新文件是 [`policies/wamoduck-getup-getup_v20.onnx`](policies/wamoduck-getup-getup_v20.onnx)，SHA-256 见上，由轮次 `2026-09-16_19-12-01_getup_v20` 的检查点 `model_3999.pt` 导出，并用 `tools/verify_onnx_provenance.py` 核验为**逐元素差 0**。
- **The fix was one reward term, and the intermediate round is recorded because it failed instructively.** The head-chain posture penalty is now **ungated** with weight **−1.0**. The round before this one **gated** that same penalty by body tilt (it only applied once the robot was nearly upright); the policy then escaped through the gate — it stayed tilted, where the penalty was zero — and measured **0/5** on the hand-over, tilt **62.28°**, and **24.24 N** of ground reaction on the head. The lesson is a reusable criterion, not an anecdote: **a penalty gated by a state the policy controls is an escape hatch**; a *reward* gate has no such failure mode, because a closed gate only withholds a bonus. / **修法是**一个**奖励项，而中间那一轮的失败也一并记录，因为它的失败很有信息量。** 头链姿态惩罚现在是**无门控**、权重 **−1.0**。中间那一轮给同一项加了"按身体倾角生效"的门（只有快站直时才生效）；结果策略从门里**逃了出去** —— 它一直歪着，那里惩罚为零 —— 接力量到 **0/5**、末态倾角 **62.28°**、头受到的地面反力 **24.24 N**。教训是一条可复用的判据而不是轶事：**用策略自己能控制的状态做门的惩罚项，就是一个逃逸口**；正**奖励**的门没有这个问题，因为门关了只是不给奖励。
- **The stricter six-axis criterion is reported alongside, and it is not yet at its target.** That criterion adds "the head must not press on the ground" and "the soles must be flat", and requires each axis to hold for ≥90 % of the last second: all six together go **0/64 → 45/64**, with per-axis rates of 56/64 (tilt), 52/64 (both feet), 58/64 (joint deviation), 61/64 (base height), 61/64 (head off the ground) and 46/64 (flat soles). The median per-axis pass rate is **100 %**, so the remaining failures are marginal rather than whole-run, but the target on record is **≥58/64** and this release does **not** meet it. / **更严的六轴口径也一并报出，而它还没到目标。** 那条口径另加"头不压地"与"脚掌平贴"，并要求每条轴在最后一秒内 ≥90 % 时刻成立：六轴一起由 **0/64** 升到 **45/64**，逐轴为 倾角 56/64、双脚着地 52/64、关节偏差 58/64、基座高度 61/64、头不压地 61/64、脚掌平贴 46/64。各轴的合格率中位是 **100 %**，所以剩下的失败是边缘的而不是整段不会，但在册的目标是 **≥58/64**，本版本**未达到**。
- **The weight was bracketed by two failed rounds, and both are recorded.** The penalty must be **ungated** (the gated round measured **0/5** on the hand-over: the policy escaped through the gate by staying tilted), but it must also stay **small enough for the rollover to remain affordable**: a round at **−1.5** measured standing at the end **3/64**, hand-over **0/5**, final tilt **68.3°** and **17.65 N** of ground reaction on the head — the stronger penalty prices out the neck fold that is the only way this machine rolls over. A third round that instead raised the *leg* posture weight (1.5 → 2.5) came back slightly worse on every axis of the six-axis criterion (**190/256** against **206/256**) while keeping the hand-over at 5/5, which closes that lever too. The published weight is **−1.0**, the only one of the three that both gets up and lands in the nominal pose. / **这个权重是被两次失败夹出来的，两次都记录在案。** 惩罚必须**无门控**（门控那一轮接力 **0/5**：策略靠"一直歪着"从门里逃了出去），但也必须**小到翻身还付得起账**：**−1.5** 那一轮末态站住 **3/64**、接力 **0/5**、末态倾角 **68.3°**、头链地面反力 **17.65 N** —— 更重的惩罚把"折脖子翻身"（这台机器唯一的翻身方式）定价出局。第三轮改去提高**腿**姿态项权重（1.5 → 2.5），结果六轴逐条略降（**190/256** 对 **206/256**），接力仍是 5/5 ⇒ 这条杠杆也关掉了。公开采用 **−1.0**，三档里唯一既起得来、又落回标称姿态的。
- **The old file is kept, not deleted, for the same reason as the sit/stand one.** `wamoduck-getup-getup_v18.onnx` stays in [`policies/`](policies/README.md) because the capability board's get-up section is a measurement *of that file*: the strict **0/64** and the **52.3°** joint deviation. It is labelled superseded in the policy table, and the board now states which numbers are the baseline and which are current. The two screen recordings that show get-up were also made on v18; [`assets/README.md`](assets/README.md) and the media manifest say so. / **旧文件保留不删，理由与坐／站那份相同。** `wamoduck-getup-getup_v18.onnx` 留在 [`policies/`](policies/README.md) 里，因为能力清单的起身一节是**对那份文件**的测量：严格口径 **0/64** 与 **52.3°** 的关节偏差。策略表里给它标了"已被取代"，能力清单现在也写明哪些数字是基线、哪些是当前值。展示起身的两段录屏同样是在 v18 上录的，[`assets/README.md`](assets/README.md) 与媒体台账里都写明了。
- **Every number here is Sim2Sim.** The three acceptance tools are the development repository's, all CPU-side except the rollouts themselves, and the CPU run on this page's own runner reproduces the new behaviour (`max_joint_dev` **11.01°**, `nominal=True`, against **52.08°** and `nominal=False` for the previous policy). There is still no hardware result anywhere in this repository. / **这里每个数字都是 Sim2Sim。** 三套验收工具都来自研发仓库（除 rollout 本身外都在 CPU 侧），而本仓库运行器自己的 CPU 复核也复现了新行为（`max_joint_dev` **11.01°**、`nominal=True`，旧版是 **52.08°**、`nominal=False`）。本仓库依然没有任何实机结果。

### 2026-09-16 — The sit/stand policy is replaced: both reported problems are fixed / 坐／站策略已替换：用户报告的两个问题都修好了

- **`sit_stand_v3` replaces `sit_stand_v2` as the published sit/stand policy, and both problems measured on the old one are fixed.** Standing jitter `mean|Δa|` **0.699 → 0.000** rad and net drift **+27.99 → +0.394 mm/s**; the sitting pose goes from a **10.05°** lean at a 0.112 m command (and **25.91°** at the old 0.085 m command) with left/right residuals of **146.09°** / **173.56°**, to a **0.225°** lean with a **0.473°** residual — the largest pair being the knees at 0.47°. Both feet are down with the CoM inside the support polygon for **100 %** of the last second. The new file is [`policies/wamoduck-sitstand-sit_stand_v3.onnx`](policies/wamoduck-sitstand-sit_stand_v3.onnx), SHA-256 `c75139732aa2890964f56a5df78b8c8c351d2fea88533ac5b1fb78aba6574163`, exported from run `2026-09-16_18-05-44_sit_stand_v3`, checkpoint `model_2499.pt`, verified by `tools/verify_onnx_provenance.py` with a **zero** element-wise difference against every actor tensor. / **`sit_stand_v3` 取代 `sit_stand_v2` 成为公开的坐／站策略，旧版上实测到的两个问题都已修好。** 站立抖动 `mean\|Δa\|` **0.699 → 0.000** rad、净漂移 **+27.99 → +0.394 mm/s**；坐姿从"指令 0.112 m 时倾 **10.05°**（旧指令 0.085 m 时 **25.91°**）、左右残差 **146.09°／173.56°**"变成"倾 **0.225°**、左右残差 **0.473°**"（最大一对是膝，0.47°）。末 1 s 内 **100 %** 时刻双脚着地且质心在支撑多边形内。新文件是 [`policies/wamoduck-sitstand-sit_stand_v3.onnx`](policies/wamoduck-sitstand-sit_stand_v3.onnx)，SHA-256 见上，由轮次 `2026-09-16_18-05-44_sit_stand_v3` 的检查点 `model_2499.pt` 导出，并用 `tools/verify_onnx_provenance.py` 核验为**逐元素差 0**。
- **The old file is kept, not deleted, and the measurements that found the problems stay next to it.** `wamoduck-sitstand-sit_stand_v2.onnx` remains in [`policies/`](policies/README.md) because the capability board's sit/stand section is a measurement *of that file*: deleting it would leave those tables unreproducible. The board now states which numbers are the baseline and which are current, in the same table. / **旧文件保留而不是删除，发现问题的那些测量也留在它旁边。** `wamoduck-sitstand-sit_stand_v2.onnx` 仍留在 [`policies/`](policies/README.md) 里，因为能力清单的坐／站一节是**对那份文件**的测量：删掉它，那些表格就无法复现。能力清单现在在同一张表里写明哪些数字是基线、哪些是当前值。
- **The seat moved from 0.085 m to 0.11241 m, because 0.085 m is geometrically unreachable.** With the trunk upright, the torso collision box's lowest corner lies **109 mm** below the base origin, so the base cannot go below **0.109 m** without the torso entering the floor. The old policy "reached" 0.094 m by leaning **25.9°** to lift that corner clear — which *is* the second reported problem, not a training shortfall. The runner's `m` toggle, its `--target-height` range, the command-range note and the file tree were all updated, and the acceptance tool reports "the command is unreachable" on a separate axis from the four axes that judge the policy, so the two are never confused. / **坐高由 0.085 m 改为 0.11241 m，因为 0.085 m 几何不可达。** 躯干直立时，躯干碰撞盒最低角点在基座原点下方 **109 mm**，基座低于 **0.109 m** 就会让躯干扎进地面。旧策略能"到" 0.094 m 是靠歪 **25.9°** 把那个角抬起来 —— 而那**正是**用户报的第二个问题，不是训练欠缺。运行器的 `m` 切换、`--target-height` 范围、指令范围说明与文件树都已同步；验收工具把"指令不可达"报在**独立于**判策略那四条轴之外的一条轴上，两者不会被混为一谈。
- **One new limitation is recorded rather than hidden: the seated pose is not a stance the walking policy can start from.** Switching to `walk` **while seated** collapses the robot — tilt **134.9°** after 6 s with **0.438 m** of travel. The bundled self-test used to perform exactly that switch; it now presses `m` to stand back up first and **asserts the stand-up itself** (0.1096 → 0.1719 m, tilt 1.31°), which is the sequence a user performs. The unsupported hand-over is stated on the [simulation page](docs/simulation.md) / [仿真指南](docs/simulation.zh-CN.md) and in [`policies/README.md`](policies/README.md), with its numbers. / **新增一条限制，如实记录而不是隐藏：坐姿不是行走策略起得来的站姿。** **还坐着**就切到 `walk` 会让机器人瘫倒 —— 6 s 后倾角 **134.9°**、位移 **0.438 m**。随仓库的自检原来做的正是这次切换；现在它先按 `m` 站起来，并**把"站起来"本身做成断言**（0.1096 → 0.1719 m、倾角 1.31°），这也正是用户会做的顺序。这条不受支持的交接连同数字写在[仿真指南](docs/simulation.zh-CN.md)／[simulation page](docs/simulation.md)与 [`policies/README.md`](policies/README.md) 里。
- **The self-test grew a check, rather than losing one.** `wamoduck_sim.py --cycle-test` now asserts **7** things instead of 6: the new one is the sit → stand transition, and the walk and rough segments now start from a standing pose (measured: walk travels **1.854 m** of the commanded 1.800 m at vx = +0.30, tilt 3.40°; rough **1.781 m**, tilt 5.58°). / **自检是**增加**了一条检查，而不是减少。** `wamoduck_sim.py --cycle-test` 现在断言 **7** 条而不是 6 条：新增的是"坐 → 站"这一步；行走与越障两段现在从站姿开始（实测：行走在 vx = +0.30 下走 **1.854 m**（指令 1.800 m）、倾角 3.40°；越障 **1.781 m**、倾角 5.58°）。
- **Every number above is CPU Sim2Sim from this repository's own runner**, except the seven-axis acceptance, which is the development repository's CPU acceptance tool (also no GPU). No policy was validated on hardware; the repository still contains no hardware result. / **以上所有数字都是本仓库运行器的 CPU Sim2Sim**，七轴验收用的是研发仓库的 CPU 验收工具（同样不用 GPU）。没有任何策略在实机上验证过；本仓库依然没有实机结果。

### 2026-09-16 — Why in-place turning cannot be trained away / 为什么"原地转"不是训练能解决的

- **The walking section of the [capability board](docs/capabilities.md) / [能力清单](docs/capabilities.zh-CN.md) now states *why* in-place turning fails, instead of listing it as an unfinished item.** A new subsection, [Why in-place turning cannot be trained away](docs/capabilities.md#why-in-place-turning-cannot-be-trained-away) / [为什么"原地转"不是训练能解决的](docs/capabilities.zh-CN.md#为什么原地转不是训练能解决的), reports three hard constraints, each with an analytic bound **and** a measured value from the same scene: the hips' yaw joints are an **internal torque pair** with a net moment of zero, so with both feet planted they can twist the torso only **±30.5°** relative to the ground (measured: **8.0°** of foot slip plus **22.5°** of torso = **30.5°**); unloading one foot would need a **59.8–60.2 mm** sideways CoM shift (stance **171.4 mm**, foot width **51.1 mm**), and the CoP was measured to equal the CoM projection to **0.000 mm**, so the requirement is exact; and with **no ankle roll** the only lever left to shift the CoM is the torso rotating about the hip-roll axes, giving a symmetric bound of **35.3 mm** (**16.5 mm** measured) or **76.0 mm** with one leg forced to its limit — measured **38.5 mm**, at which point the robot is already tilted **28.5°** against a **30°** fall line. / **能力清单的行走一节现在写明"原地转"失败的原因，而不是把它列为未完成项。** 新增小节给出三条硬约束，每条都有**解析上界**和**同一场景里的实测值**：两个髋偏航关节是**内力矩对**、对整机力矩和恒为 0，所以两脚贴地时只能让躯干相对地面扭 **±30.5°**（实测：脚打滑 **8.0°** 加躯干 **22.5°** = **30.5°**）；卸载一只脚需要质心横移 **59.8–60.2 mm**（站距 **171.4 mm**、脚宽 **51.1 mm**），而 CoP 与质心投影实测相等、差 **0.000 mm**，所以这个要求是精确的；而在**没有踝侧摆**的前提下，能挪动质心的唯一力臂是躯干绕髋侧摆轴转，对称上界 **35.3 mm**（实测 **16.5 mm**）、把一条腿掰到限位 **76.0 mm** —— 实测 **38.5 mm**，而那时机器人已倾 **28.5°**，摔倒线是 **30°**。
- **Eleven drive patterns were tried, and none of them accumulates.** Triangle waves, sine scrubbing, scissoring, a four-phase ratchet, and slow ramps into both end stops were run for 10 s each on the **unmodified training MJCF**: the seven that stayed upright reoriented the **feet in the world** by only **−12° to +8°** against a **286°** command, and every pattern that turned further was on the ground within **0.96–1.22 s** (post-fall tumbling excluded). Lifting one foot does reach **0.000 N** of load, but only at the joint limits, at **28.47°** of tilt, for **0.8 %** of the time — that is falling onto one foot, not a controlled single support. / **试了 11 种驱动方式，没有一种能累积。** 三角波、正弦搓地、剪刀式、四相棘轮、慢升到两个限位，各在**未经改动的训练用 MJCF** 上跑 10 s：站满 10 s 的 7 种，**脚在世界系里**只重定向 **−12° 到 +8°**（指令是 **286°**）；转得更多的那几种**都在 0.96–1.22 s 内倒地**（倒地后的翻滚已剔除）。抬一只脚确实能把法向力压到 **0.000 N**，但只在关节限位处、倾角 **28.47°**、时间占比 **0.8 %** 时出现 —— 那是"倒在一只脚上"，不是可控单支撑。
- **The deliverable is restated, and so is the fix.** Turning happens **while moving**. Measured with the published policy through the published runner (10 s runs, yaw command **0.5 rad/s = 28.6 deg/s**): at **0.10 and 0.15 m/s the robot does not walk at all** — **0.012–0.018 m** of travel in 10 s, with or without the yaw command — so at those speeds the question of tracking the yaw command does not arise, and a figure like "1 % yaw tracking at 0.15 m/s" describes a robot that is standing still. From **0.20 m/s** it does turn while walking: **62 % / 69 % / 75 %** of the command at 0.20 / 0.30 / 0.40 m/s, on arcs of **measured** radius **0.72 / 0.93 / 1.11 m**, which is larger than the **commanded** ratio vx / \|wz\| (0.40 / 0.60 / 0.80 m) by exactly the under-tracking factor. The tightest arc actually **measured** is therefore **R ≈ 0.7 m** at **vx ≥ 0.20 m/s**. Standing still, the torso can be re-oriented **once** by up to **±30.5°** relative to the ground, which is enough to aim the head or a camera but does not accumulate. True in-place rotation is a **hardware** change: an ankle-roll (or equivalent coronal-plane) degree of freedom so the legs can lean and the CoM can move ≥ 60 mm, or a waist yaw joint. [`README.md`](README.md) / [`README.zh-CN.md`](README.zh-CN.md) and [`docs/simulation.md`](docs/simulation.md) / [`docs/simulation.zh-CN.md`](docs/simulation.zh-CN.md) were reworded to match, so the repository no longer implies that another training round would fix it. / **交付口径与修法都改写清楚。** 转向发生在**行进中**。用公开策略走公开运行器实测（每次 10 s，偏航指令 **0.5 rad/s = 28.6 度/秒**）：在 **0.10 与 0.15 m/s 时机器人根本不会走** —— 10 s 只移动 **0.012–0.018 m**，给不给偏航指令都一样 —— 所以那两个速度上"偏航跟不跟得上"这个问题不成立，而"0.15 m/s 下偏航跟踪 1 %"这种说法描述的其实是一台站着不动的机器人。从 **0.20 m/s** 起它确实边走边转：在 0.20 / 0.30 / 0.40 m/s 下分别跟踪到指令的 **62 % / 69 % / 75 %**，走的是**实测**半径 **0.72 / 0.93 / 1.11 m** 的弧线，比**指令比** vx / \|wz\|（0.40 / 0.60 / 0.80 m）更大，差值正是欠跟踪的倍数。因此**实测到**的最紧弧线是 **R ≈ 0.7 m**（**vx ≥ 0.20 m/s**）。静止时躯干可以**一次性**相对地面重定向至多 **±30.5°**，够用来对准头部或相机，但不可累积。真正的原地转属于**硬件改动**：加踝侧摆（或等效冠状面自由度）让腿能侧倾、质心能横移 ≥ 60 mm，或加腰部偏航关节。README 与仿真指南的中英两版都已同步改写，本仓库不再暗示"再训一轮就能解决"。
- **How it was measured, and how the ruler was checked first.** Plain MuJoCo on **CPU**, training MJCF unmodified, **two independent runs producing byte-identical JSON**, and a self-test that calibrates the ruler before measuring anything: a box the size of the real sole, hinged about z, starts turning at **0.635 N·m**, i.e. an effective lever of **34.5 mm**, inside the analytic bracket of **25.5–47.7 mm**; it also asserts that the CoP equals the CoM projection. One negative result is recorded with it: an earlier idea of measuring the load split by welding the base to the world was discarded, because that weld carries **63.6 %** of the vertical load. / **怎么测的、尺子怎么先验的。** 纯 **CPU** MuJoCo、训练用 MJCF 原样不动、两次独立运行产出的 JSON **逐字节相同**；工具在测任何东西之前先自检标定尺子：与真实脚掌同尺寸的 box 只留绕 z 铰链，实测起转阈值 **0.635 N·m**，即等效力臂 **34.5 mm**，落在解析区间 **25.5–47.7 mm** 内；同时断言 CoP 与质心投影相等。一条反面结论也一并记录：早期想用"把基座焊死到世界"来测承重分配的办法被弃用，因为那个焊点会分走 **63.6 %** 的垂向载荷。
- **What is not claimed.** No hardware test was possible; the arc-turning figures come from **single CPU rollouts** (one run per speed, no multi-seed or multi-environment sweep), so **R ≈ 0.7 m** and the yaw-tracking percentages above 0.20 m/s should be read as indicative rather than precise. For the CoM-shift constraint the page reports both the analytic **upper bound** and the measured value, because the bound is looser (35.3 mm against 16.5 mm measured). No policy was retrained or re-exported for this entry, and no other number on the capability board changed. / **没有声称的部分。** 没有实机可测；弧线转向的数字来自**单次 CPU rollout**（每个速度只跑一次，没有多种子、没有多环境扫描），所以 **R ≈ 0.7 m** 与 0.20 m/s 以上的偏航跟踪百分比只能当参考量级，不要当精确值。质心横移那条约束，页面同时给出解析**上界**与实测值，因为上界更松（35.3 mm 对实测 16.5 mm）。本次没有重训或重导任何策略，能力清单上也没有其他数字发生变化。
- **Pages that named the wrong walking checkpoint were corrected in the same pass.** [`docs/simulation.md`](docs/simulation.md) / [`docs/simulation.zh-CN.md`](docs/simulation.zh-CN.md) and [`docs/capabilities.zh-CN.md`](docs/capabilities.zh-CN.md) still said the published walking ONNX is `model_6000.pt`; they now say `model_6749.pt`, the run's final checkpoint, matching the replacement in the entry below. / **同一轮里也改正了写错行走检查点的页面。** 仿真指南与能力清单中文版原本仍写着公开的行走 ONNX 是 `model_6000.pt`；现在改为该轮次的最终检查点 `model_6749.pt`，与下面那条替换一致。
- Scope is unchanged: **Sim2Sim only**, no hardware result anywhere in this repository. / 口径不变：**仅 Sim2Sim**，本仓库没有任何实机结果。

### 2026-09-16 — The published walking policy is replaced with its run's final checkpoint / 公开的行走策略已换为该轮次的最终检查点

- **[`policies/wamoduck-walk-walk_v4r.onnx`](policies/wamoduck-walk-walk_v4r.onnx) was replaced, and the checkpoint this repository names for it changed from `model_6000.pt` to `model_6749.pt`.** The first version was published on 2026-09-16 14:47 and was copied out of the run directory (`2026-09-16_12-01-21_walk_v4r`) **while that run was still training**. mjlab rewrites the run directory's ONNX on **every checkpoint save** — `mjlab/tasks/velocity/rl/runner.py` calls `super().save()` and then `export_policy_to_onnx()` into the same path — so the copy captured the save that wrote `model_6000.pt` (14:42:16), and the run's **final** save, `model_6749.pt` (15:10:28, twenty-eight minutes later), overwrote the file locally after the copy had been taken and never reached this repository. Both files are valid exports of the **same** run; the one published now is the run's last checkpoint, which is also the checkpoint the development repository's own measurements of `walk_v4r` load. New SHA-256 `8ec4fd347a22d69937550681e58e6d2cd511748b067677bcef345fdae5546ea2`, replacing `ff1379550b1c107ab1287dd85627466dae235580e96da8e4d1b77033305d393d`; byte count is unchanged at **773096**. / **[`policies/wamoduck-walk-walk_v4r.onnx`](policies/wamoduck-walk-walk_v4r.onnx) 已替换，本仓库为它标注的检查点也从 `model_6000.pt` 改为 `model_6749.pt`。** 最初那版于 2026-09-16 14:47 发布，是从轮次目录（`2026-09-16_12-01-21_walk_v4r`）里拷出来的，而**那一轮当时还在训练**。mjlab 在**每次保存检查点**时都会把轮次目录里那份 ONNX 重写一遍（`mjlab/tasks/velocity/rl/runner.py` 先 `super().save()` 再 `export_policy_to_onnx()`，写的是同一个路径），所以拷走的那份对应的是写入 `model_6000.pt` 的那次保存（14:42:16）；而该轮次的**最终**保存 `model_6749.pt`（15:10:28，二十八分钟后）在本地把同一个文件覆盖掉了，从未进过本仓库。两份文件都是**同一轮次**的合法导出；现在公开的是该轮次最后一个检查点，也是研发仓库自己关于 `walk_v4r` 的测量所加载的那一个。新 SHA-256 为 `8ec4fd347a22d69937550681e58e6d2cd511748b067677bcef345fdae5546ea2`，原为 `ff1379550b1c107ab1287dd85627466dae235580e96da8e4d1b77033305d393d`；字节数不变，仍是 **773096**。
- **The provenance claim on the [`policies/`](policies/README.md) page is now a tool, not a recollection.** The development repository's `tools/verify_onnx_provenance.py --onnx <file> --run <run> --expect <checkpoint>` compares the ONNX initializers (`mlp.*`, plus the in-graph observation normalizer) against `actor_state_dict` in **every** `model_*.pt` of the run, element by element, and exits non-zero unless exactly one checkpoint matches. An exported actor is a byte-level copy, so the difference is **exactly 0**, and that is what every row of the table reports. Its `--selftest` proves the criterion accepts the right checkpoint and rejects both a perturbed one and one with a missing tensor. **All five published policies were re-verified under it: 5/5 exact matches** — the four files that did not change were checked too, so the correction above is the only one needed. / **[`policies/`](policies/README.md) 页上的来源声称现在是一个工具，而不是一句回忆。** 研发仓库的 `tools/verify_onnx_provenance.py --onnx <文件> --run <轮次> --expect <检查点>` 把 ONNX 的 initializer（`mlp.*` 以及图内的观测归一化）与该轮次**每一个** `model_*.pt` 里的 `actor_state_dict` **逐元素**比对，除非恰好有一个检查点精确匹配，否则以非零码退出。actor 的导出是逐字节拷贝，所以差值是**恰好 0** —— 表里每一行报的都是这个。它的 `--selftest` 证明该判据会接受正确的检查点、并拒绝被扰动的、以及缺张量的两种情形。**五个公开策略都用它重验了一遍：5/5 精确匹配** —— 没变的那四个也一并查了，所以上面这处更正是唯一需要的一处。
- **What did not change.** No policy was retrained and no measurement was redone for this entry. `model_6000.pt` and `model_6749.pt` are not the same weights — the largest element-wise difference across the exported actor tensors is **7.6e-2** — and **nothing here claims that one is better than the other**; the replacement is about publishing the run's final save, not about a measured improvement. The capability board's walking row is unaffected because it measures `walk_r3`, a checkpoint that was never published; the known gaps (in-place turning at 0.5 rad/s yields **+0.3 deg** in 10 s, and side-stepping carries large uncommanded yaw) were measured on other checkpoints and are unchanged. / **没有变的部分。** 本次没有重训任何策略、也没有重做任何测量。`model_6000.pt` 与 `model_6749.pt` **不是**同一组权重 —— 导出张量里逐元素最大差 **7.6e-2** —— 而**这里没有一句说哪一个更好**；这次替换是为了公开该轮次的最后一份保存，不是因为在测量上变好了。能力清单的行走那一行不受影响，因为它测的是 `walk_r3`，那个检查点从未公开；已知不足（原地转 0.5 rad/s 在 10 s 内只转 **+0.3°**、侧移伴随大量未指令自转）是在别的检查点上测的，同样不变。
- **The trap is recorded because it repeats.** A training run rewrites its own export directory as it goes, so **publishing from a run whose training is still in progress** silently publishes whichever save was latest at that moment, and the file name on disk will not tell you which one it was. Verify provenance by name, shape and value against the `.pt` files — not by file name, and not by the `final checkpoint` wording in a manifest. / **这个坑值得记下来，因为它会重复。** 训练过程会不断重写自己的导出目录，所以**在训练还在进行时从该轮次发布**，等于悄悄发布了当时最新的那一次保存，而磁盘上的文件名不会告诉你它是哪一次。核验来源要比对**名字、形状与数值**（对着那些 `.pt`），不要看文件名，也不要相信清单里"final checkpoint"这类措辞。
- Scope is unchanged: **Sim2Sim only**, no hardware result anywhere in this repository, and no claim about the physical robot. / 口径不变：**仅 Sim2Sim**，本仓库没有任何实机结果，也没有对实物机器人做任何声称。

### 2026-09-16 — The action order is adjudicated: joint-tree order / 动作顺序已裁决：关节树顺序

- **A self-contradiction inside this repository is resolved.** [`wamoduck_sim.py`](wamoduck_sim.py) reads the **14**-dimension policy output in **joint-tree order** (`ctrl_ids = [0, 2, 4, 6, 8, 1, 3, 5, 7, 9, 10, 11, 12, 13]`), while [`ros2/wamoduck_ros2/wamoduck_ros2/model_contract.py`](ros2/wamoduck_ros2/wamoduck_ros2/model_contract.py) read it in **actuator** order (MJCF `<actuator>` order). The two disagree for `action[1]` to `action[8]` — the actuator reading makes `action[1]` the right hip yaw, the tree reading makes it the left hip roll — so exactly one of them could be right. It is **joint-tree order**, and the **ROS 2 side was corrected**, not the runner: `ACTION_TO_JOINT` is now the identity. / **本仓库内部的一处自相矛盾已解决。** [`wamoduck_sim.py`](wamoduck_sim.py) 把 **14** 维策略输出按**关节树顺序**解读（`ctrl_ids = [0, 2, 4, 6, 8, 1, 3, 5, 7, 9, 10, 11, 12, 13]`），而 [`ros2/wamoduck_ros2/wamoduck_ros2/model_contract.py`](ros2/wamoduck_ros2/wamoduck_ros2/model_contract.py) 按**执行器**顺序（MJCF `<actuator>` 顺序）解读。两者在 `action[1]` 到 `action[8]` 上冲突 —— 执行器序读法里 `action[1]` 是右髋偏航，树序读法里是左髋侧摆 —— 所以只可能有一个是对的。答案是**关节树顺序**，而且改的是 **ROS 2 那一侧**，不是运行器：`ACTION_TO_JOINT` 现在是恒等置换。
- **A new, direct observation settles it; it is not another reading of the code.** A one-hot probe was run in **plain MuJoCo, CPU only** (`mujoco 3.10.0`), on the **training MJCF**, through the same action path the runner uses: for `i` = 0 … 13 the action vector is set to a one-hot `+0.4` rad on channel `i` and zero elsewhere, applied as `q_target = default_joint_pos + action_scale × action`, and the resulting change in **all 14 joint angles** is recorded. The result is a **14×14** response matrix that is a **permutation matrix**: every row and every column has exactly one dominant entry, and the dominant change is the full **22.5°** (0.4 rad) against off-diagonal coupling of at most **0.16°** — a dominance of at least **140×**. / **一条新的直接观测定了案，而不是又读了一遍代码。** 在**纯 CPU 的 MuJoCo**（`mujoco 3.10.0`）里、用**训练用的 MJCF**、走运行器同一条动作路径做了一次 one-hot 探针：`i` = 0 … 13 逐个把动作向量做成"第 `i` 通道 `+0.4` rad、其余为 0"，按 `q_target = default_joint_pos + action_scale × action` 施加，记下**全部 14 个关节角**的变化。结果是一张 **14×14** 的响应矩阵，而且是一个**置换矩阵**：每行每列恰有一个主导项，主导变化是完整的 **22.5°**（0.4 rad），非对角耦合最多 **0.16°** —— 主导度至少 **140×**。
- **What the matrix says, channel by channel.** Channel `i` moves joint-tree joint `i` and nothing else: `action[0]` = left hip yaw, `action[1]` = **left** hip roll, `action[4]` = left ankle, `action[5]` = right hip yaw, `action[10]` … `action[13]` = neck pitch, head pitch, head yaw, head roll. That is exactly the `ctrl_ids` reading, and it is **not** the actuator-order reading, which would move a different joint for `action[1]` to `action[8]`. The probe reproduces identically on the published [`models/wmduck/mjcf/robot_walk.xml`](models/wmduck/mjcf/robot_walk.xml) and in a grounded variant with a floor and real contacts, so the result is not an artefact of one scene. / **矩阵逐个通道说的内容。** 通道 `i` 只让关节树第 `i` 个关节动，别的都不动：`action[0]` = 左髋偏航、`action[1]` = **左**髋侧摆、`action[4]` = 左踝、`action[5]` = 右髋偏航、`action[10]` … `action[13]` = 颈俯仰、头俯仰、头偏航、头侧倾。这正是 `ctrl_ids` 的读法，而**不是**执行器序读法 —— 后者会让 `action[1]` 到 `action[8]` 动到另一个关节。该探针在已发布的 [`models/wmduck/mjcf/robot_walk.xml`](models/wmduck/mjcf/robot_walk.xml) 上、以及在补了地面与真实接触的落地变体里给出完全相同的结果，所以这不是某一个场景的假象。
- **Three further lines of evidence agree, and they are listed in the code.** mjlab's own resolver (`Entity.find_joints_by_actuator_names`) run against the training MJCF returns already-joint-order ids `[0 … 13]` — the identity — because it filters the joint list in tree order and its matching call returns in that order; every published policy's ONNX metadata records `joint_names` as `left_hip_yaw, left_hip_roll, …, head_roll`; and the 2×2 ablation over observation order × action order already on record leaves only tree/tree standing, walking, crouching and getting up. All four are written into the [`model_contract`](ros2/wamoduck_ros2/wamoduck_ros2/model_contract.py) module docstring. / **另外三条证据一致，并且都写进了代码里。** mjlab 自己的解析器（`Entity.find_joints_by_actuator_names`）在训练 MJCF 上返回已按关节树顺序排列的 `[0 … 13]`（即恒等置换），因为它先按树序过滤关节表、匹配结果又按该表顺序返回；每个已发布策略的 ONNX 元数据里 `joint_names` 都是 `left_hip_yaw, left_hip_roll, …, head_roll`；而已在册的"观测顺序 × 动作顺序"2×2 消融里，只有树序／树序还能站、能走、能蹲起、能起身。四条都写进了 [`model_contract`](ros2/wamoduck_ros2/wamoduck_ros2/model_contract.py) 的模块文档。
- **Corrected: the ROS 2 contract module, its tests, and every page that restated the actuator reading.** [`model_contract.py`](ros2/wamoduck_ros2/wamoduck_ros2/model_contract.py) (`ACTION_TO_JOINT` → identity, with the old permutation kept in the test as a named constant so it cannot come back silently), [`test_model_contract.py`](ros2/wamoduck_ros2/test/test_model_contract.py), [`policy_interface.py`](ros2/wamoduck_ros2/wamoduck_ros2/policy_interface.py), [`test_policy_interface.py`](ros2/wamoduck_ros2/test/test_policy_interface.py), [`policy_node.py`](ros2/wamoduck_ros2/wamoduck_ros2/policy_node.py), [`policy_runner.py`](ros2/wamoduck_ros2/wamoduck_ros2/policy_runner.py), [`frame_codec.py`](ros2/wamoduck_ros2/wamoduck_ros2/frame_codec.py), [`bridge_stub.py`](ros2/wamoduck_ros2/wamoduck_ros2/bridge_stub.py), [`ros2/README.md`](ros2/README.md) / [`ros2/README.zh-CN.md`](ros2/README.zh-CN.md), [`ros2/verification/README.md`](ros2/verification/README.md), and the joint-order sections of [`docs/simulation.md`](docs/simulation.md) / [`docs/simulation.zh-CN.md`](docs/simulation.zh-CN.md). `action_to_joint_target()` is kept as the single application site; it is an element-wise `default_joint_pos + action_scale × action` now, and the function exists so that a future order change has one place to land. / **已改正：ROS 2 契约模块、它的测试，以及每一处复述执行器序读法的页面。** ... `action_to_joint_target()` 保留为唯一的施加位置，现在是逐元素的 `default_joint_pos + action_scale × action`；保留这个函数是为了将来顺序若变只有一处要改。
- **The power-on warning on the motor-ID pages is rewritten from "not settled" to "settled in simulation, still unverified on hardware".** The permutation `bus_id(action_index) = [1, 3, 5, 7, 9, 2, 4, 6, 8, 10, 11, 12, 13, 14]` is unchanged; what changed is that the internal disagreement it warned about is gone. The warning that **remains** is the one that matters: none of the four lines of evidence was measured on a physical robot, so the permutation still has to be confirmed on the machine, one bus ID at a time, before the servos are energised. Bus direction and polarity, the termination resistors, and the ID assignment as actually programmed into the servos are unverified in the same way. / **电机 ID 页上的上电警告已从"尚未裁决"改写为"已在仿真里裁决、实机仍未验证"。** 置换 `bus_id(action_index) = [1, 3, 5, 7, 9, 2, 4, 6, 8, 10, 11, 12, 13, 14]` 本身没变；变的是它所警告的那处内部分歧已经消失。**仍然保留**的那条警告才是关键：四条证据没有一条是在实物机器人上测出来的，所以在给舵机上电之前，该置换仍需在真机上逐个总线 ID 核对。每一路总线的方向与极性、终端电阻、以及舵机里实际烧录的 ID 分配，同样未在实机上验证。
- Scope is unchanged: **Sim2Sim only** for every number above, no hardware result anywhere in this repository, and no policy was retrained or re-exported for this change. / 口径不变：以上所有数字**仅在 Sim2Sim 内**，本仓库依然没有任何实机结果，本次改动也没有重训或重导任何策略。

### 2026-09-16 — Motor bus IDs, the three CAN-FD buses, and the action permutation / 电机总线 ID、三路 CAN-FD 总线与动作置换

- Added [`hardware/motor_ids.csv`](hardware/motor_ids.csv) with [`motor_ids.json`](hardware/motor_ids.json), [`motor_ids.md`](hardware/motor_ids.md) and [`motor_ids.zh-CN.md`](hardware/motor_ids.zh-CN.md), plus the position drawing [`assets/wamoduck-motor-ids.png`](assets/wamoduck-motor-ids.png). The table lists all **15** motors with the bus ID of each, the joint it drives, the physical bus it sits on, and whether a published policy drives it. / 新增 [`hardware/motor_ids.csv`](hardware/motor_ids.csv) 与 [`motor_ids.json`](hardware/motor_ids.json)、[`motor_ids.md`](hardware/motor_ids.md)、[`motor_ids.zh-CN.md`](hardware/motor_ids.zh-CN.md)，以及位置图 [`assets/wamoduck-motor-ids.png`](assets/wamoduck-motor-ids.png)。表中列出全部 **15** 个电机：各自的总线 ID、驱动的关节、所在的物理总线、以及是否由公开策略驱动。
- **This is hardware and interface information, not a performance claim.** Nothing on these pages says that a policy stands or walks, in simulation or on the robot; there is still no hardware result anywhere in this repository. / **这是硬件与接口信息，不是性能声称。** 这些页面没有一句说策略能站或能走 —— 无论是仿真还是实机；本仓库依然没有任何实机结果。
- The bus IDs come from the maintainer's own workbook `List_MotorID_CANFD.xlsx`, sheet `Sheet1`, **15** data rows, and every one of the **15** joint names was checked one by one against [`models/wmduck/wmduck.urdf`](models/wmduck/wmduck.urdf). All **15** match, so nothing had to be guessed. / 总线 ID 来自维护者自己的 `List_MotorID_CANFD.xlsx` 工作簿 `Sheet1` 表，共 **15** 行数据；**15** 个关节名已逐个与 [`models/wmduck/wmduck.urdf`](models/wmduck/wmduck.urdf) 核对，**15** 个全部对得上，因此没有任何需要猜的地方。
- One correction is recorded rather than silently applied: the source table spells the bus 2 joint `Rightt_hip_yaw`, which is a typographical error. The URDF and the MJCF both spell it `right_hip_yaw`, and the `note` field of the CSV keeps the original spelling on the record. / 有一处更正是**记录在案**而不是悄悄改掉的：源表把总线 2 上的关节拼作 `Rightt_hip_yaw`，属拼写笔误。URDF 与 MJCF 都拼作 `right_hip_yaw`，CSV 的 `note` 字段保留了原始拼写。
- **The three physical buses are recorded as the maintainer stated them on 2026-09-16.** The **AT32** main control board runs **three** CAN-FD buses on **XT30(2+2)** connectors, and those connectors carry power and CAN-FD together: one bus for the **left leg**, one for the **right leg**, and one for the **neck and head**. Each carries **5** motors, so **3 × 5 = 15**, which is exactly the **15** rows of the source table — the bus split and the table agree. / **三路物理总线按维护者 2026-09-16 的说明记录。** **AT32** 主控板走**三路** CAN-FD 总线，均用 **XT30(2+2)** 端子，该端子把电源与 CAN-FD 一起承载：**左下肢**一路、**右下肢**一路、**脖子及头部**一路。每路挂 **5** 个电机，即 **3 × 5 = 15**，恰好等于源表的 **15** 行 —— 总线划分与源表完全吻合。
- **The IDs on a single bus are not consecutive, and the page says so in the open.** The left-leg bus carries **1, 3, 5, 7, 9**; the right-leg bus carries **2, 4, 6, 8, 10**; the neck-and-head bus carries **11, 12, 13, 14, 15**. A left-leg bus does **not** use 1, 2, 3, 4, 5. / **单条总线上的 ID 不是连号，页面把这一点明写在最前面。** 左下肢总线是 **1、3、5、7、9**，右下肢是 **2、4、6、8、10**，脖子及头部是 **11、12、13、14、15**。左下肢总线**不**用 1、2、3、4、5。
- **Two orders that are not the same are written out side by side.** The bus ID order (**1, 2, 3 ... 15**, left/right interleaved) is the order of the `<actuator>` block in [`robot_walk.xml`](models/wmduck/mjcf/robot_walk.xml), the MJCF the policies were trained in. The **14**-dimension action vector, however, is read as **joint-tree order** (left leg 5, right leg 5, neck and head 4), so firmware and any host program have to permute once: `bus_id(action_index) = [1, 3, 5, 7, 9, 2, 4, 6, 8, 10, 11, 12, 13, 14]` for action index **0** to **13**. / **把两种并不相同的顺序并排写明。** 总线 ID 顺序（**1、2、3 …… 15**，左右交错）就是这些策略训练时所用 MJCF [`robot_walk.xml`](models/wmduck/mjcf/robot_walk.xml) 里 `<actuator>` 块的顺序；而 **14** 维动作向量是按**关节树顺序**解读的（左腿 5、右腿 5、颈头 4），因此固件与任何上位机程序都必须做一次置换：动作下标 **0** 到 **13** 对应 `bus_id(action_index) = [1, 3, 5, 7, 9, 2, 4, 6, 8, 10, 11, 12, 13, 14]`。
- **`mouth` is separated from the rest explicitly.** The published policies output **14** values, not **15**, because they have no beak axis. `mouth` is bus ID **15** and a real revolute joint in the URDF, but it is not in the action vector: `driven_by_policy` is `false` for it and its `action_index` is empty. / **`mouth` 被显式区分出来。** 公开策略输出的是 **14** 个值而不是 **15** 个，因为它们没有嘴部这一轴。`mouth` 的总线 ID 是 **15**、在 URDF 里也是真实的转动关节，但它不在动作向量里：它的 `driven_by_policy` 为 `false`、`action_index` 为空。
- **A prominent power-on warning sits on both pages.** The permutation has **not** been verified on a physical robot, so nothing should be energised on the strength of it; a wrong joint order mis-drives a joint and, in this project's own simulation, collapses the robot within a second. It is also **not settled**: an internal deployment-contract file reads the action vector in **actuator order**, and this repository's ROS 2 module [`model_contract.py`](ros2/wamoduck_ros2/wamoduck_ros2/model_contract.py) does the same, so under that reading `action[1]` targets bus ID **2** where this page sends it to bus ID **3** — the disagreement is unresolved. The bus direction and polarity, the termination resistors, and the ID assignment as actually programmed into the servos are unverified on hardware in the same way. / **两份页面都带一条醒目的上电警告。** 该置换**尚未**在实机上验证，因此不应据此给任何东西上电；关节顺序接错会错误驱动关节，而在本项目自己的仿真里，顺序接错会让机器人在一秒内瘫倒。它同样**尚未裁决**：一处内部部署契约文件按**执行器顺序**读动作向量，本仓库的 ROS 2 模块 [`model_contract.py`](ros2/wamoduck_ros2/wamoduck_ros2/model_contract.py) 也是同样读法，按那种读法 `action[1]` 的目标是总线 ID **2**，而本页把它发往总线 ID **3** —— 这个分歧尚未裁决。每一路总线的方向与极性、终端电阻、以及舵机里实际烧录的 ID 分配，也同样未在实机上验证。 *(Superseded later the same day: the action order was adjudicated as **joint-tree order** and the warning was rewritten — see the entry above. The hardware-verification half of this warning still stands. / 当天晚些时候已被取代：动作顺序裁决为**关节树顺序**，该警告已改写 —— 见上一条。这条警告里"实机未验证"的那一半仍然成立。)*
- The drawing is an **export of the deck's only slide**, produced with Microsoft PowerPoint at **2400 × 1350** pixels and published unmodified. The deck contains **two** embedded CAD renders and no others, and those renders carry no bus IDs on their own: the numbers and the `Left` / `Right` labels are separate text shapes drawn over them, so an export is the only faithful form of the annotation. Neither the source workbook nor the source deck is redistributed here, so no `.xlsx` or `.pptx` enters this repository. / 位置图是**该幻灯片唯一一页的导出**，由 Microsoft PowerPoint 生成、尺寸 **2400 × 1350** 像素、原样公开。该幻灯片里只有**两张**内嵌 CAD 渲染图、没有别的图，而这两张图本身并不带总线 ID：数字与 `Left` / `Right` 标签是叠在其上的独立文本框，所以"把这一页导出"才是标注的唯一忠实形式。源工作簿与源幻灯片都不随本仓库分发，因此本仓库不会引入任何 `.xlsx` 或 `.pptx`。
- Refreshed both ledgers and both entry points: [`assets/media-manifest.json`](assets/media-manifest.json) and [`asset-manifest.json`](asset-manifest.json) gained the new PNG and the four `hardware/motor_ids.*` files with their SHA-256 and byte counts, both READMEs gained the file-tree line, a "Wire it up" bullet and a routing row, and [`hardware/README.md`](hardware/README.md) and [`assets/README.md`](assets/README.md) were updated. The repository's consistency, link, table, and line-ending checks were run green before the commit. / 两份台账与两个入口都已刷新：[`assets/media-manifest.json`](assets/media-manifest.json) 与 [`asset-manifest.json`](asset-manifest.json) 收录了新的 PNG 与四个 `hardware/motor_ids.*` 文件及其 SHA-256 与字节数；两份首页都加了文件树条目、"接线"小节与一行路由；[`hardware/README.md`](hardware/README.md) 与 [`assets/README.md`](assets/README.md) 也已更新。提交前四项检查（一致性、链接、表格、换行符）均已跑绿。
- Scope is unchanged: **Sim2Sim only** for behaviour, no hardware result anywhere, and no new measurement of the robot. / 口径不变：行为部分**仅 Sim2Sim**，本仓库没有任何实机结果，也没有对这台机器人做任何新的实测。

### 2026-09-16 — Why the beak exists: planned uses, and what the model has today / 嘴部为什么存在：计划用途，以及模型今天的实际情况

- Added a **planned, not implemented** section to [`docs/roadmap.md`](docs/roadmap.md), plus one row in that page's deliverables table, explaining why bus ID **15** exists at all. This repository keeps a single bilingual [`docs/roadmap.md`](docs/roadmap.md) rather than a `roadmap.md` plus `roadmap.zh-CN.md` pair, so the new section is bilingual inside that file, sentence by sentence, the way the rest of the page is. / 在 [`docs/roadmap.md`](docs/roadmap.md) 里新增一节**计划中、未实现**的内容，并在该页交付表里加了一行，说明总线 ID **15** 到底为什么存在。本仓库的路线图是**单份双语** [`docs/roadmap.md`](docs/roadmap.md)，没有 `roadmap.md` 与 `roadmap.zh-CN.md` 这样一对文件，因此新增内容在同一文件内逐句双语，与该页其余部分一致。
- **Why it exists.** The beak is not in the **14**-dimension action vector any published policy outputs: it is a spare independent degree of freedom held back for human-robot interaction, and that is what explains the difference between **15** motors on the bus and **14** action values. / **它为什么存在。** 嘴部不在任何公开策略输出的 **14** 维动作向量里：它是一个被留给人机交互的备用独立自由度，这也正是"总线上 **15** 个电机、动作只有 **14** 个值"这一差异的原因。
- **Planned use 1 — sound feedback.** Close and open the beak in response to a human voice, with a module carrying speech recognition to be added later. / **计划用途 1 —— 声音反馈。** 听到人声后做张合嘴的反馈，后续会接一个带语音识别功能的模块。
- **Planned use 2 — holding a small ball.** Grip and hold a small ball in the cavity of the mouth, together with the on-board binocular structured-light depth camera. / **计划用途 2 —— 含住小球。** 用嘴里的空腔夹住并含住小球，结合机上的双目结构光深度相机。
- **The status is written as "planned, not implemented", in those words, and no date is promised.** The section also states what the model actually contains today, so that "planned" cannot be read as "supported". / **状态按"计划中，未实现"这几个字写明，也没有承诺任何日期。** 该节同时写出模型今天的实际情况，以免"计划中"被读成"已支持"。
- `mouth` is **one** revolute joint — parent `head_roll_link`, axis `0 1 0`, range **0** to **102.5** degrees in [`joint_limits.csv`](models/wmduck/joint_limits.csv) — so the mechanism is a bite plus a cavity hold, not a pinch. / `mouth` 是**单个**转动关节 —— 父 link 为 `head_roll_link`、轴向 `0 1 0`、在 [`joint_limits.csv`](models/wmduck/joint_limits.csv) 里范围是 **0** 到 **102.5** 度 —— 因此机制是"咬合 + 靠空腔含住"，不是捏取。
- **The simulation the policies are trained and published in has no cavity in the mouth.** In [`robot_walk.xml`](models/wmduck/mjcf/robot_walk.xml) — standing, sit/stand, walking, rough terrain — the **entire head chain has no collision geometry at all**. In [`robot_groundcontact.xml`](models/wmduck/mjcf/robot_groundcontact.xml) — get-up — the mouth is **one solid box**, `size="0.051375 0.041883 0.016277"`, and a MuJoCo box `size` is a half-extent, so that box is about **0.103 × 0.084 × 0.033** m with no cavity in it. The URDF is the opposite: `mouth_link`'s collision is the `Mouth.stl` mesh itself, so the CAD cavity is retained there. Simulating "holding a ball" therefore has to be built separately, with a collision representation of the cavity, a free ball body, and friction and contact tuning, and with the stability of concave-body and mesh contact verified on its own. / **公开策略训练与运行所用的仿真里，嘴里没有空腔。** 在 [`robot_walk.xml`](models/wmduck/mjcf/robot_walk.xml)（站立、坐站、行走、越障）里**整个头链没有任何碰撞体**；在 [`robot_groundcontact.xml`](models/wmduck/mjcf/robot_groundcontact.xml)（起身）里，嘴是**一个实心盒** `size="0.051375 0.041883 0.016277"`，而 MuJoCo 盒体的 `size` 是半边长，因此该盒约 **0.103 × 0.084 × 0.033** m、内部没有空腔。URDF 恰好相反：`mouth_link` 的碰撞体**就是 `Mouth.stl` 网格本身**，CAD 空腔在那里保留了。因此"含住球"的仿真必须另做：要给空腔一个碰撞表示、加一个自由小球刚体、调摩擦与接触参数，并单独验证凹体与网格接触的稳定性。
- **No model contains a camera, and the repository makes no perception claim.** `camera`, `depth`, and `stereo` appear nowhere in the URDF or in either MJCF, so the depth-camera plan has no representation in the simulation or in a perception chain yet; it is a new subsystem. / **模型里没有任何相机，本仓库也没有做感知声称。** `camera`、`depth`、`stereo` 在 URDF 与两个 MJCF 里都不出现，因此深度相机方案目前在仿真与感知链路里都没有表示，属于新子系统。
- **Holding a ball is a question of geometry and friction, not of torque.** The beak uses the same motor as the other **14**: **15** instances of the same HTDW3532 specification, rated **0.6** N·m. / **含球的成败取决于几何与摩擦，不是扭矩。** 嘴部电机与其余 **14** 个相同：**15** 个实例同为 HTDW3532、额定 **0.6** N·m。
- Wired the two pages together rather than leaving the beak plan in one place: the `mouth` row of [`hardware/motor_ids.csv`](hardware/motor_ids.csv) and [`motor_ids.json`](hardware/motor_ids.json) now say that bus ID **15** is reserved for interaction features and point at the roadmap, the closing bullet of both bus ID guides says the same in prose, and the roadmap links back to both guides. / 把两处内容互相接通，而不是让嘴部计划只待在一个地方：[`hardware/motor_ids.csv`](hardware/motor_ids.csv) 与 [`motor_ids.json`](hardware/motor_ids.json) 里 `mouth` 那一行现在写明总线 ID **15** 预留给交互功能并指向路线图，两份总线 ID 说明的对应条目也用文字写了同一件事，而路线图反过来链回这两份说明。
- Scope is unchanged: **planned work is not a result.** Nothing in this entry was implemented, nothing was measured, and there is still no hardware result anywhere in this repository. / 口径不变：**计划不是成果。** 本条没有任何内容被实现、也没有任何测量，本仓库依然没有任何实机结果。

### 2026-09-16 — Two reported `sitstand` problems, measured / 用户报告的 `sitstand` 两个问题，已实测

- A user playing the published demo reported two problems with the sit/stand policy, in their own words: with `sitstand` selected the duck **buzzes in place while standing**, and sitting down does not give "the head and torso vertical to the ground with the two legs braced symmetrically". Both were then measured — the report is quoted as the user gave it, and every number below is our own measurement taken afterwards. / 一位用户在实际玩公开 demo 时报告了坐／站策略的两个问题，原话是：切到 `sitstand` 后**鸭子站立时会原地抖动**，坐下也不是"头和躯干直立于地面、左右两腿对称对撑"的坐姿。两条随后都做了实测 —— 报告按用户原话引用，下面每个数字都是我们事后自己测的。
- The measurement used this repository's own published single-file runner, **CPU only**, MuJoCo **3.10.0** / ONNX Runtime **1.30.0** / NumPy **2.5.3**, 500 control steps (**10.0 s**) per run, spawn `nominal`, flat floor — `python wamoduck_sim.py --policy sitstand --target-height 0.175 --headless --steps 500`, the same command at `0.085`, and `python wamoduck_sim.py --policy stand --headless --steps 500` as the control. The per-step traces were recorded with a temporary harness outside the repository that drives `wamoduck_sim.Demo` and the same observe → act → apply → step loop the headless mode uses, so the run is the documented one and not a second implementation. / 测量用的是本仓库公开的单文件运行器，**纯 CPU**，MuJoCo **3.10.0**／ONNX Runtime **1.30.0**／NumPy **2.5.3**，每次运行 500 个控制步（**10.0 s**），出生点 `nominal`，平地 —— 命令为 `python wamoduck_sim.py --policy sitstand --target-height 0.175 --headless --steps 500`、把高度换成 `0.085` 的同一条命令、以及作为对照的 `python wamoduck_sim.py --policy stand --headless --steps 500`。逐控制步的轨迹由仓库外的一个临时测量脚本记录，它驱动的是 `wamoduck_sim.Demo` 与无界面模式同一条 observe → act → apply → step 循环，所以这是文档里写的那一次运行，不是第二套实现。
- **The two figures already on record reproduce.** The run holds **0.094 m** against a 0.085 m command and leans **~26°**, matching the numbers this repository already published for that command. What is new is the jitter and the left/right symmetry. / **已有记录的两个数字被重现了。** 这次运行在指令 0.085 m 时维持 **0.094 m**、倾斜约 **26°**，与本仓库此前公布的该指令数字一致。新测到的是**抖动**与**左右对称性**。
- **Problem 1 — the standing posture buzzes in place.** At a 0.175 m command the robot is upright (final tilt **0.44°**, base height **0.1762 m**) and never settles: action jitter, `mean abs(delta a)` per control step — the same metric row 1 of the capability board uses — is **0.229** over the whole 10 s, **0.235** after the first 1.0 s and **0.236** in the last 1.0 s, with a maximum single step of **1.313**; tilt std **0.403°** (**0.396°** in the last second, so it is a sustained limit cycle rather than a settling transient); base-height std **1.10 mm**; mean absolute joint velocity **1.69 rad/s** with a peak of **10.11 rad/s**. The `stand` policy on the same metric and the same run length gives **9.9e-5**, **2.9e-7** and **4.1e-8**, i.e. about **six orders of magnitude** quieter, so this is a property of the sit/stand policy and not of the runner. Both soles are down in only **92.2 %** of the steps after the first second and the feet carry **45.46 N** on average against a **36.80 N** weight — the buzz is pushing the ground — and "in place" is approximate, because it also travels **0.263 m** over the 10 s. / **问题一 —— 站立姿态原地抖动。** 0.175 m 指令下机器人是直立的（末态倾角 **0.44°**、基座高度 **0.1762 m**），但**始终不收敛**：动作抖动（每控制步的 `mean abs(delta a)`，正是能力清单第 1 行所用的那个指标）整 10 s 为 **0.229**、去掉前 1.0 s 为 **0.235**、末 1.0 s 为 **0.236**，单步最大 **1.313**；倾角标准差 **0.403°**（末 1 s 为 **0.396°**，所以这是持续的极限环而不是会衰减的过渡过程）；基座高度标准差 **1.10 mm**；关节速度绝对值均值 **1.69 rad/s**、峰值 **10.11 rad/s**。同一个指标、同样运行长度下 `stand` 策略是 **9.9e-5**、**2.9e-7**、**4.1e-8**，安静约**六个数量级**，所以这是坐／站策略本身的性质、不是运行器的性质。去掉前 1 s 后只有 **92.2 %** 的步数双脚同时着地，双脚平均承担 **45.46 N** 而整机重量是 **36.80 N** —— 抖动的力是蹬在地面上的 —— 而"原地"也只是近似：10 s 里它同时还挪了 **0.263 m**。
- **Problem 2 — the sitting posture is neither upright nor left/right symmetric.** At a 0.085 m command the pose is **quiet** (it reaches a static pose inside about 1 s: `mean abs(delta a)` **4.4e-7** and tilt std **1.3e-4°** in the last second), so the jitter is a standing-height problem only; pressing `m` mid-run lands on the same pose. But that quiet pose is a **25.89°** lean (roll **−15.99°**, pitch **+20.64°**) held at **0.0943 m** instead of the commanded 0.085 m (**+9.3 mm**), with the head — `head_roll_link` — **25.62°** off vertical and the neck **25.44°** off, because the head chain's own joints are all within **0.6°** of zero and simply inherit the trunk's lean. It is also not standing on two feet: `base_link_body_collision`, the pelvis, is in contact with the floor in **100 %** of the last second carrying **7.16 N** of the **36.83 N** total (**19.4 %** of the weight), and the right foot rests on a single edge contact **22 mm** above its sole geometry while the left foot is flat on three. / **问题二 —— 坐姿既不直立也不左右对称。** 0.085 m 指令下这个姿态是**安静的**（约 1 s 内到达静态姿态：末 1 s 的 `mean abs(delta a)` 为 **4.4e-7**、倾角标准差 **1.3e-4°**），所以抖动只是站立高度的问题；运行途中按 `m` 切过去也落到同一个姿态。但那个安静的姿态是 **25.89°** 的倾斜（横滚 **−15.99°**、俯仰 **+20.64°**），维持在 **0.0943 m** 而不是指令的 0.085 m（**+9.3 mm**）；**头**（`head_roll_link`）偏离竖直 **25.62°**、颈 **25.44°** —— 因为头链自身的关节全部在零附近 **0.6°** 以内，只是整体继承了躯干的倾斜。它也不是靠两只脚站着：`base_link_body_collision`（骨盆）在末 1 s 的 **100 %** 步数里与地面接触，承担 **36.83 N** 里的 **7.16 N**（体重的 **19.4 %**）；右脚靠单点边缘接触立着、比脚底几何高 **22 mm**，而左脚是三点平贴。
- **The left/right symmetry was measured with the sign convention stated first, because the two sides do not share a sign.** The MJCF mirrors the ranges of the two `hip_yaw` and two `hip_roll` joints (`left_hip_yaw` **−1.7279 to +0.5323 rad** against `right_hip_yaw` **−0.5323 to +1.7279 rad**; `left_hip_roll` **−1.1153 to +0.4311 rad** against `right_hip_roll` **−0.4311 to +1.1153 rad**), while `hip_pitch`, `knee` and `ankle` have identical ranges on both sides; a direct probe agrees — `left_hip_roll = +0.3 rad` moves the left sole outward from y = **+0.0846 m** to **+0.1116 m** while `right_hip_roll = +0.3 rad` moves the right sole inward from y = **−0.0846 m** to **−0.0523 m**. So a mirrored pose has `hip_yaw` and `hip_roll` at **opposite signs** and `hip_pitch`, `knee`, `ankle` equal. At the sitting height, `hip_roll` and `knee` agree to within **0.6°** but the other three do not match at all: `hip_yaw` residual **−119.32°**, `hip_pitch` **+173.54°**, `ankle` **−142.33°** — the left hip is flexed **+128.29°** against a right hip of **−45.26°**, and the left ankle **−93.97°** against **+48.36°**. At the standing height the same measurement shows a staggered stance (one leg forward, one back), and the `stand` policy keeps all five pairs inside **0.6°**, which is the control showing the convention is applied correctly. / **左右对称性是先把符号约定写清再测的，因为两侧并不共用同一个符号。** MJCF 自己就把两个 `hip_yaw` 与两个 `hip_roll` 的关节范围镜像了（`left_hip_yaw` **−1.7279 到 +0.5323 rad** 对 `right_hip_yaw` **−0.5323 到 +1.7279 rad**；`left_hip_roll` **−1.1153 到 +0.4311 rad** 对 `right_hip_roll` **−0.4311 到 +1.1153 rad**），而 `hip_pitch`、`knee`、`ankle` 两侧范围完全相同；直接探针给出同样的结论 —— `left_hip_roll = +0.3 rad` 把左脚底从 y = **+0.0846 m** 向外移到 **+0.1116 m**，而 `right_hip_roll = +0.3 rad` 把右脚底从 y = **−0.0846 m** 向内移到 **−0.0523 m**。因此镜像姿态下 `hip_yaw` 与 `hip_roll` 的左右值**符号相反**，而 `hip_pitch`、`knee`、`ankle` 相等。在坐姿高度上，`hip_roll` 与 `knee` 相差不到 **0.6°**，另外三对则完全对不上：`hip_yaw` 残差 **−119.32°**、`hip_pitch` **+173.54°**、`ankle` **−142.33°** —— 左髋屈曲 **+128.29°** 对右髋 **−45.26°**，左踝 **−93.97°** 对 **+48.36°**。在同一测量里，站立高度收敛到的是一个前后错步的姿态；而 `stand` 策略五对全部在 **0.6°** 以内，这正是"符号约定用对了"的对照。
- **Status: known, and not fixed.** Neither problem is fixed in this release, and the run recorded here is the evidence that they are real rather than a reading of the viewer. The training-side work they imply has not been done, and no fix is promised. / **状态：已知，未修复。** 本版本**没有**修复其中任何一个问题；这里记录的运行是"它们确实存在、而不是看窗口看错了"的证据。它们所指向的训练侧工作尚未进行，也没有承诺任何修复。
- Documented in [measured capabilities](docs/capabilities.md) / [实测能力清单](docs/capabilities.zh-CN.md) (the full tables, the mirror-sign convention, and the user's expectation written as three testable statements), in [Run the trained policies in MuJoCo](docs/simulation.md) / [在 MuJoCo 里跑训练好的策略](docs/simulation.zh-CN.md) (a new `sitstand` subsection plus a `Known gaps` bullet, and the "limits worth knowing" line at the top raised from three to four), and in both READMEs (the sit/stand row and the "what still does not work" list). / 已写入[实测能力清单](docs/capabilities.zh-CN.md)／[英文版](docs/capabilities.md)（完整表格、镜像符号约定，以及把用户期望改写成三条可检验陈述）、[仿真指南](docs/simulation.zh-CN.md)／[英文版](docs/simulation.md)（新增 `sitstand` 小节与一条 `已知不足`，并把开头的"值得先知道的局限"从三条提到四条）、以及两份首页（坐／站那一行与"仍然不行的部分"清单）。
- **This release defines no target sitting pose.** The three statements on the capability page are the user's expectation restated as assertions so that training has something to aim at; they are not a measured target and not thresholds adopted here. Where a tolerance is quoted it is one this repository already uses (tilt below **8°** for "upright"; the strict-standing criteria do not otherwise apply to a sitting pose, because they require a base height above 0.15 m that a 0.085 m sit command can never reach). / **本版本没有定义任何目标坐姿。** 能力清单上的那三条陈述是把用户的期望改写成断言、好让训练有个可对的目标；它们不是测出来的目标，也不是本次采纳的阈值。凡标注了容差的地方用的都是本仓库**已有**的口径（"直立"是倾角低于 **8°**；严格站姿的其余口径**不**适用于坐姿，因为它们要求基座高度高于 0.15 m，而 0.085 m 的坐姿指令永远不可能达到）。
- Scope is unchanged: **Sim2Sim only**, CPU MuJoCo, and no hardware result anywhere. No internal `sitstand` acceptance log exists, so nothing here reproduces a private measurement. / 范围不变：**仅 Sim2Sim**，CPU 上的 MuJoCo，本仓库没有任何实机结果。内部**没有** `sitstand` 的验收日志，所以这里没有一条是在复现内部测量。

### 2026-09-16 — Documentation readability pass / 文档可读性整理

- Rewrote both READMEs so a visitor from GitHub meets "what is this" and "what can it do" **before** "how do I run it", and reaches the technical detail last. The measurement figures that used to sit inside dense paragraphs are now small tables, and the limits are stated as a list in the open rather than inside parentheses. **Not one figure changed**: every number in both READMEs is the same number it was before, and each one still points at the tool or page that produced it. / 重写中英文首页，让从 GitHub 点进来的人先看到"这是什么""能做什么"，**再**看"怎么跑起来"，技术细节放在最后。原先埋在密集段落里的实测数字抽成了小表格，局限也从括号里搬到明面上逐条列出。**一个数字都没有改**：两份首页里的每个数字都与改前相同，并且仍然指向产出它的工具或页面。
- Added the missing `ros2/` entry point to both READMEs: it now appears in the file tree, in the "where to go next" table, and in a dedicated section that states its verification status as a table — verified only on **WSL2 Ubuntu 24.04, x86_64**; the RDK X5's **ARM64** userspace is unverified; hardware, `policy_node` end to end, and Gazebo/MoveIt are all unverified or not started; and RViz adds no physics. / 补上两份首页里缺失的 `ros2/` 入口：现在它出现在文件树、"接下来去哪里"表和专门一节里，该节用一张表写明验证状态 —— 只在 **WSL2 Ubuntu 24.04、x86_64** 上验证过；RDK X5 的 **ARM64** 用户空间未验证；硬件、`policy_node` 端到端、Gazebo／MoveIt 均未验证或未开始；RViz 不提供任何物理。
- Added a "5 minutes" path to both READMEs: install `mujoco`/`onnxruntime`/`numpy`, run `python wamoduck_sim.py`, and a table of what each of `1`-`5` puts on screen. / 两份首页都加了"5 分钟"路径：装 `mujoco`／`onnxruntime`／`numpy`，跑 `python wamoduck_sim.py`，再用一张表说明按 `1`-`5` 各自会看到什么。
- Added a "three limits worth knowing before you start" line near the top of both simulation guides — no in-place turning, a sideways command that drags the robot round, `getup` not reaching the saved nominal pose, and no hardware result anywhere — each pointing at the existing [Known gaps](docs/simulation.md#known-gaps-stated-plainly) section. / 在两份仿真指南开头加了"上手前值得先知道的三条局限" —— 不会原地转、侧移会把机器人带得打转、`getup` 回不到保存的标称姿态，以及没有任何实机结果 —— 每条都指向原有的[已知不足](docs/simulation.zh-CN.md#已知不足直说)一节。
- Added a plain-language summary list at the top of both measured-capability pages: what works, what does not, and that none of it is hardware. / 两份实测能力清单开头都加了白话总览：哪些能用、哪些不能用、以及这些都不是实机数据。
- **The technical contract was not touched.** The observation layout with its offsets and units, the joint-tree order, `q_target = default_joint_pos + action`, the fact that the ONNX already contains the normalizer, and the 50 Hz / `decimation = 4` / `0.005 s` timing are unchanged word for word, because they are what a reader needs in order to run the files at all. / **技术契约一个字都没动。** 带偏移与单位的观测布局、关节树顺序、`q_target = default_joint_pos + action`、ONNX 内已含归一化、以及 50 Hz／`decimation = 4`／`0.005 s` 的时序，都逐字保留 —— 它们是别人能否跑起来的关键。
- Verified the bilingual rule mechanically rather than by eye: a script compares the number-token multiset and the link-target set of each language pair. README, capabilities, and simulation now match exactly. Two wording-only fixes were needed in the Chinese simulation guide, where "0" stood where the English said "zeros" (**零** now, no value changed). No other language pair was modified in this pass. / 用脚本而不是肉眼核对双语规则：比较每对页面的数字 token 多重集与链接目标集合。首页、实测能力清单、仿真指南三对现已完全一致。中文仿真指南里有两处措辞需要调整 —— 英文写"zeros"的地方中文写的是"0"（现改为**零**，数值未变）。其余语言对这些页面本次没有改动。
- Scope is unchanged: **Sim2Sim only**, no hardware result anywhere, and no new measurement. Editing these Markdown files did not change any hash in [`asset-manifest.json`](asset-manifest.json), because no file recorded there was modified. / 范围不变：**仅 Sim2Sim**，本仓库没有任何实机结果，也没有新增任何测量。本次改动没有影响 [`asset-manifest.json`](asset-manifest.json) 里的任何哈希，因为没有修改其中记录的任何文件。

### 2026-09-16 — One demo for all five policies / 一个 demo 切换全部五个策略

- [`wamoduck_sim.py`](wamoduck_sim.py) is now **one demo instead of five separate runs**. The viewer starts on `--policy` (`stand` by default) and switches between every published policy while it runs: `1`/`2`/`3`/`4`/`5` for `stand`/`getup`/`sitstand`/`walk`/`rough`, and `Tab` or `n` for the next one in that order. In plain language: walking, sitting down, standing up, and the 1 cm terrain are now reachable in one window, without restarting the script. / [`wamoduck_sim.py`](wamoduck_sim.py) 从"跑五次"变成**一个 demo**：窗口从 `--policy`（默认 `stand`）指定的策略启动，运行中可切换全部五个公开策略 —— `1`/`2`/`3`/`4`/`5` 依次对应 `stand`/`getup`/`sitstand`/`walk`/`rough`，`Tab` 或 `n` 切到该顺序里的下一个。也就是说：走路、坐下、起身、1 cm 越障现在都在同一个窗口里，不必重启脚本。
- Switching between `stand`, `sitstand`, `walk`, and `rough` — the four policies that share `robot_walk.xml` — **keeps the robot state**: only the ONNX actor and the observation assembly (48 / 49 / 51 values) are swapped in place, so the pose, the velocity, and the commands the user set all survive. `last_action` is zeroed on a switch, because that observation term is the new policy's own memory of its previous output. Entering or leaving `getup` is the one switch that **cannot** keep the state: `getup` is trained with the head chain colliding, so it needs `robot_groundcontact.xml`, and the runner reloads that MJCF, says on screen why the state had to be reset, and re-spawns the robot lying down (`lie-back`) on the way in and in the nominal stance on the way out. / 在共用 `robot_walk.xml` 的四个策略（`stand`、`sitstand`、`walk`、`rough`）之间切换会**保留机器人状态**：只原地替换 ONNX actor 与观测装配（48／49／51 维），因此姿态、速度与用户设过的指令都留下来了。切换时把 `last_action` 归零，因为那一项观测属于新策略对自己上一步输出的记忆。进入或离开 `getup` 是唯一**无法**保留状态的切换：`getup` 是用"头链会碰撞"的模型训练的，需要 `robot_groundcontact.xml`，运行器会重新加载该 MJCF，在屏幕上说明状态为什么必须重置，进入时按躺姿 `lie-back` 重新出生、离开时按标称站姿出生。
- `walk` ↔ `rough` now switches the **terrain** as well as the policy, without reloading anything: the 1 cm curbs are compiled into the model and moved in front of the robot (0.3 m apart, starting 0.3 m ahead of its current `x`), and the unused ones are parked below the floor with their collision switched off. `rough` therefore gets 3 curbs by default and `walk` stays on the flat floor, so the two policies are now what their names say; `--terrain-level N` still overrides both, and then every policy runs on N curbs. / `walk` ↔ `rough` 现在连**地形**一起切换，且不重新加载任何东西：1 cm 台阶本来就编译在模型里，切换时摆到机器人前方（间距 0.3 m，从机器人当前 `x` 前方 0.3 m 起），没用到的那些停在地面以下并关掉碰撞。因此 `rough` 默认带 3 个台阶、`walk` 保持平地，两个策略终于名副其实；`--terrain-level N` 仍可覆盖两者，此时每个策略都在 N 个台阶上跑。
- Unified the keys into one table and made every key answer for itself. **A key is never ignored in silence**: pressing a key the current policy has no channel for — `m` on `walk`, or an arrow key on `sitstand` — now prints what the key would need and what the policy actually observes (`[key] 'm' needs a body-height command, but the current policy 'walk' observes vx/vy/wz -- ignored (nothing changed)`), a key the runner does not bind at all says so and points at `h`, and `h`/`?` reprints the table with each row marked as active or "NO EFFECT with this policy". Every switch prints the new policy, its observation vector, its command channel, its MJCF, and its terrain. / 把按键统一成一张表，并且**每个键都会自己回答**：按了当前策略没有对应通道的键（`walk` 上的 `m`、`sitstand` 上的方向键）会打印"这个键需要哪种指令、当前策略实际观测哪种指令"（`[key] 'm' needs a body-height command, but the current policy 'walk' observes vx/vy/wz -- ignored (nothing changed)`），完全没绑定的键也会说明并指向 `h`，按 `h`／`?` 可再次打印键表，每一行都标注是 active 还是"在当前策略上无效"。每次切换都会打印新策略、观测向量、指令通道、MJCF 与地形。
- The viewer window now names the policy on screen: top-left `policy: walk` is the policy that is **running** and bottom-left `selected: walk` is the one that was last **asked for**, beside the observation size, the MJCF and terrain, and the live command values (`cmd vx… vy… wz…`, or the sit/stand height). The two names differ only when a switch was refused, which is exactly the case where seeing it matters; the overlay is refreshed only when its text changes, and it is written again on the window that a model reload reopens. If a MuJoCo build has no viewer text overlay, the runner says so once and keeps the policy name in the terminal. / 查看器窗口里现在直接写着策略名：左上角 `policy: walk` 是**正在运行**的策略，左下角 `selected: walk` 是最近一次**选中**的策略，旁边是观测维度、MJCF 与地形、以及当前指令值（`cmd vx… vy… wz…`，或坐／站的高度）。两个名字只有在切换被拒绝时才会不同 —— 那正是需要看见它的时候；文字只在内容变化时刷新，模型重载后重开的窗口同样会写上。若某个 MuJoCo 构建没有查看器文字叠加功能，运行器会提示一次，并继续把策略名打印在终端里。
- The viewer window is reopened when a switch reloads the MJCF, because a passive MuJoCo viewer holds one model and cannot be re-pointed at another. If that reopen ever fails, the runner says so and returns a non-zero status instead of looking like the switch crashed the demo; a first window that will not open at all still fails loudly, as before. / 切换重载 MJCF 时会重新打开查看器窗口 —— 被动查看器只持有一个模型，无法原地改指另一个。若这次重开失败，运行器会说明情况并返回非零状态，而不是让它看起来像"切换把 demo 弄崩了"；而首次开窗失败仍和以前一样直接报错。
- Added `--cycle-test`, a headless switching self-test that presses `1`→`2`→`3`→`4`→`5` **through the same key handler the keyboard uses** and checks each segment. On our CPU machine (MuJoCo 3.12.0, ONNX Runtime 1.28.0, NumPy 2.4.6), 300 control steps (6.0 s) per policy: `stand` ends at tilt **0.54°** and `base_z` **0.1770 m**; `getup` reloads, starts lying at **0.0920 m** and ends standing at **0.1782 m** (tilt 8.14°); `sitstand` toggled with `m` drops from **0.1748 m** to **0.0945 m**; `walk` **keeps** the crouched state across the switch and travels **1.730 m** of a commanded 1.800 m at `vx = +0.30`; `rough` travels **1.774 m** of 1.800 m over its 3 curbs. 6/6 checks pass, including a forward check that re-spawns after all five switches and reproduces the single-policy `walk` run exactly (**dx = +1.482 m**, dy = −0.328 m in 5.0 s). / 新增 `--cycle-test`：一套无界面切换自检，用**键盘同一个按键处理函数**依次按 `1`→`2`→`3`→`4`→`5`，并对每一段做断言。在我们的 CPU 机器上（MuJoCo 3.12.0、ONNX Runtime 1.28.0、NumPy 2.4.6），每个策略 300 个控制步（6.0 s）：`stand` 末态倾角 **0.54°**、`base_z` **0.1770 m**；`getup` 重载模型后从躺着的 **0.0920 m** 起到站立的 **0.1782 m**（倾角 8.14°）；`sitstand` 按 `m` 后从 **0.1748 m** 降到 **0.0945 m**；`walk` 跨越切换**保留**蹲姿并走完指令 1.800 m 中的 **1.730 m**（`vx = +0.30`）；`rough` 在 3 个台阶上走完 1.800 m 中的 **1.774 m**。6/6 全部通过，其中包含一项"五次切换后重新出生再前进"的复核，它**完全复现**单策略 `walk` 运行（5.0 s 内 **dx = +1.482 m**、dy = −0.328 m）。
- Recorded the part of the switching test that is a limitation rather than a success: because the sitstand → walk switch keeps the state on purpose, `walk` inherits a **crouched robot at 25.7° of tilt with a 0.085 m height command still in effect** and turns **112°** while recovering, so that segment's 1.730 m of travel is mostly along its own new heading rather than along `+x`. That is the same uncommanded-rotation weakness the walk release notes already record; the segment asserts travel, not heading, and the page says so in the same words. / 把切换自检里属于**不足**而不属于成绩的那一部分也写下来了：因为 sitstand → walk 这次切换是**有意**保留状态的，`walk` 接手的是一个**蹲着的、倾角 25.7°、且 0.085 m 高度指令仍然生效**的机器人，恢复过程中转了 **112°**，所以这一段的 1.730 m 大部分是沿它自己转向后的前方走的、而不是沿 `+x`。这正是行走发布说明里已记录的"未指令自转"弱点；该段断言的是**有位移**而不是朝向，文档里也用同样的措辞写明了这一点。
- Documented the switching behaviour, the unified key table, and the switching test in [Run the trained policies in MuJoCo](docs/simulation.md) / [在 MuJoCo 里跑训练好的策略](docs/simulation.zh-CN.md), and pointed both READMEs at the single demo. The English and Chinese pages were updated sentence by sentence so that every key, number, and command is identical in both. / 在[仿真指南](docs/simulation.zh-CN.md)与[英文版](docs/simulation.md)里写明切换行为、统一键表与切换自检，并把两份首页改成"一个 demo"的说法。中英两页逐句对应更新，保证每个按键、每个数字、每条命令两边一致。
- Recomputed the `wamoduck_sim.py` entry in [`asset-manifest.json`](asset-manifest.json), because that ledger records the hash of the published file and the file changed: **36,937 → 70,764 bytes**, new SHA-256 `2111d4d7aa060921d0a0d39415adc5d4c25d7436f205641147ad230c8752df8c`, with the repository's consistency check green afterwards. / 重算了 [`asset-manifest.json`](asset-manifest.json) 里 `wamoduck_sim.py` 的条目 —— 该台账记录公开文件的哈希，而文件变了：**36,937 → 70,764 字节**，新 SHA-256 为 `2111d4d7aa060921d0a0d39415adc5d4c25d7436f205641147ad230c8752df8c`，之后仓库一致性终检为全绿。
- Scope is unchanged: **Sim2Sim only**, CPU MuJoCo, and no hardware result anywhere. / 范围不变：**仅 Sim2Sim**，CPU 上的 MuJoCo，本仓库没有任何实机结果。

### 2026-09-16 — Five trained policies you can run in MuJoCo / 五个可以在 MuJoCo 里自己跑的训练策略

- Added [`policies/`](policies/README.md) with five ONNX actors — `wamoduck-stand-stand_v3.onnx` (`model_1499.pt`), `wamoduck-getup-getup_v18.onnx` (`model_3999.pt`), `wamoduck-sitstand-sit_stand_v2.onnx` (`model_2499.pt`), `wamoduck-walk-walk_v4r.onnx` (`model_6000.pt`), and `wamoduck-rough-rough_v2.onnx` (`model_5999.pt`). Runs and checkpoints were resolved with the development repository's `run_select.py` rules, and every published file was confirmed to be the export of exactly the named checkpoint by rebuilding the actor from the `.pt` file and comparing it with the ONNX initializers. / 新增 [`policies/`](policies/README.md)，包含五个 ONNX actor。轮次与检查点按研发仓库 `run_select.py` 的规则解析，并用 `.pt` 重建 actor 与 ONNX 权重逐项比对，确认每个公开文件确实由所指检查点导出。 *(Superseded later the same day: the walking file was replaced with that run's final checkpoint, `model_6749.pt` — its 6000-iteration checkpoint was copied while the run was still training. The other four rows were re-verified and are unchanged. / 当天晚些时候已被取代：行走那个文件换成了该轮次的最终检查点 `model_6749.pt` —— 原来的 6000 轮检查点是在训练还在跑时拷走的。其余四行已复验，未变。)*
- Added [`models/wmduck/mjcf/`](models/wmduck/mjcf/README.md) — the **training-time** MJCF models `robot_walk.xml` (used by standing, sit/stand, walking, and rough terrain) and `robot_groundcontact.xml` (used by get-up, which needs the head chain to collide so the robot can lie down). Each file differs from the training file in exactly one attribute, `meshdir="."` → `meshdir=".."`, so they load the 20 meshes already published in this repository. The 20 mesh files are **byte-identical** to the training meshes; all 20 SHA-256 digests match. / 新增训练时使用的 MJCF 模型。每个文件与训练文件只差一个属性 `meshdir`，以便加载本仓库已有的 20 个网格；20 个网格与训练用的逐字节相同，SHA-256 全部一致。
- Added [`wamoduck_sim.py`](wamoduck_sim.py), a single-file CPU runner that imports only `mujoco`, `onnxruntime`, and `numpy` — no mjlab, torch, rsl_rl, or GPU. It reproduces training timing (50 Hz, `decimation = 4`, `timestep = 0.005 s`), has an interactive viewer with keyboard twist commands, `--spawn lie-back` and four other lying poses for get-up, `--terrain-level N` for 1 cm curbs, a headless self-test mode, and a `--check` mode that re-derives the observation wiring against MuJoCo instead of trusting the code. / 新增单文件 CPU 运行器，只依赖 `mujoco`、`onnxruntime`、`numpy`。它复现训练时序，带交互窗口与键盘速度指令、五个躺姿出生点、`--terrain-level N` 台阶、无界面自检，以及一个拿 MuJoCo 自身重新推导观测接线的 `--check` 模式。
- Documented the contract in [Run the trained policies in MuJoCo](docs/simulation.md) / [在 MuJoCo 里跑训练好的策略](docs/simulation.zh-CN.md): the observation layout with per-term offsets and units (48 / 49 / 51), the **14 joints in joint-tree order**, `q_target = default_joint_pos + 1.0 × action` with `default_joint_pos` all zeros and no policy-side clipping, and the fact that **the ONNX already contains the observation normalizer** — so the client must feed raw observations and must never normalize again. The page also explains why the bundled MJCF must be used instead of the URDF. / 在仿真指南里逐项写明契约：带偏移与单位的观测布局、**按关节树顺序排列的 14 个关节**、动作换算与"策略侧不截断"、以及 **ONNX 内已含观测归一化**（因此必须喂原始观测、绝不再归一化），并说明为什么必须用随附的 MJCF 而不是 URDF。
- Verified all five policies on **CPU only** through the published runner and recorded the commands and output: `stand` holds 0.54 deg of tilt and 1 mm of drift over 5 s (passing even the strict nominal-stance criterion), `getup` stands up from all five published lying poses in 6 s, and `walk` covers 1.482 m of a commanded 1.500 m at 0.3 m/s with 0.328 m of unwanted lateral drift. / 在**纯 CPU** 上用公开运行器验证五个策略并记录了命令与输出：`stand` 5 s 内保持 0.54° 倾角与 1 mm 漂移（严格标称口径也通过）；`getup` 从五个公开躺姿在 6 s 内站起；`walk` 在 0.3 m/s 下走完指令 1.500 m 中的 1.482 m，同时侧向漂移 0.328 m。
- Measured, rather than assumed, that the **joint-tree order** is the correct one. A 2×2 ablation over observation order × action order shows that only tree/tree works, for every policy: `stand` 0.54 deg versus ~135 deg for all three wrong wirings; `walk` 1.482 m versus collapse; `sitstand` crouches and holds versus collapse; `getup` stands in **5/5** lying poses versus **1/5**, **0/5**, **0/5**. The MJCF `<actuator>` block is in a different (left/right alternating) order, so this is a real trap and it is documented as one. / 用**测量**而不是假设确认了正确的顺序是**关节树顺序**：观测顺序 × 动作顺序的 2×2 消融显示只有树序／树序可用，且对每个策略都成立。MJCF 的 `<actuator>` 块是另一种（左右交替）顺序，因此这是一个真实的坑，已在文档中写明。
- Recorded the known gaps with the same weight: walking's **in-place turning does not work** (0.5 rad/s produced +0.3 deg in 10 s) and **side-stepping carries large uncommanded yaw** (+520.4 deg); the published walking policy is `walk_v4r`, which is **not** the `walk_r3` checkpoint the capability board measured; `getup` still does not reach the strict nominal pose (52 deg of joint deviation at the end); `sitstand` holds 0.094 m when asked for 0.085 m. / 同等记录已知不足：行走的**原地转不会**、**侧移伴随大量未指令自转**；公开的行走策略是 `walk_v4r`，**不是**能力清单实测的 `walk_r3`；`getup` 仍未回到严格标称姿态；`sitstand` 在要求 0.085 m 时维持 0.094 m。
- Updated both READMEs (a new "Run the trained policies in MuJoCo" section, the development-progress and At-a-glance sections, and the included-files tree), both [measured capability](docs/capabilities.md) pages, and this changelog. **Scope is unchanged: Sim2Sim only.** These policies were verified in MuJoCo on the CPU; no physical robot was involved and no policy here has been tested on hardware. / 更新中英文首页（新增"在 MuJoCo 里跑训练好的策略"一节、开发进度与模型概览、以及包含文件树）、两份[实测能力清单](docs/capabilities.zh-CN.md)与本更新记录。**范围不变：仅 Sim2Sim。** 这些策略只在 CPU 上的 MuJoCo 里验证过，没有涉及实物机器人。

### 2026-09-16 — Simulated push-recovery demo clips / 推倒恢复的仿真演示动图与全长录像

- Added four media files under `assets/`: [wamoduck-push-normal.gif](assets/wamoduck-push-normal.gif), [wamoduck-pushed-down-recover.gif](assets/wamoduck-pushed-down-recover.gif), [wamoduck-getup-struggle.gif](assets/wamoduck-getup-struggle.gif), and the full-length [wamoduck-force-test-demo.mp4](assets/wamoduck-force-test-demo.mp4). / 在 `assets/` 下新增四个媒体文件：平常推一把（7 s）、被推倒后站回标称（7 s）、最剧烈的起身片段（34 s），以及全长录像（1:49.37）。
- **They are simulation, not hardware.** All four are screen recordings of the MuJoCo simulation running this project's trained policies (`stand_v3` for standing against pushes, `getup_v18` for getting up); no physical robot appears in them. Each clip is one selected take that shows the behaviour and is not an acceptance test — the measured rates stay on the [measured capability board](docs/capabilities.md) / [实测能力清单](docs/capabilities.zh-CN.md). / **它们是仿真，不是实机。** 四段都是 MuJoCo 仿真录屏，跑的是本项目训练出来的策略（站立抗扰 `stand_v3`、起身 `getup_v18`），画面里没有实物机器人。每段都是挑选出来的单次片段、不是验收测试；实测比例仍以[实测能力清单](docs/capabilities.zh-CN.md)为准。
- The training-progress overlay ball visible in the original screen capture was removed from all four; the published files are **not** the untouched original recording. After removal the same bright-green detector that locates the ball reports **0 pixels**, and the magenta chroma-key residue the capture left in the top-right corner of every frame was repainted from neighbouring ground pixels (0 magenta pixels measured afterwards). 0 magenta residue also holds for the MP4, and the encoding details are recorded in the manifest. / 原始录屏里的「训练进度悬浮球」已从四段中全部移除，公开文件**不是**未经处理的原始录屏。移除后，用于定位悬浮球的同一套亮绿检测给出 **0 像素**；录屏留在每帧右上角的品红抠图色块也用相邻地面像素修补过（修补后测得 0 品红像素），MP4 同样为 0，编码细节记在清单里。
- Embedded the three GIFs in the capability page with bilingual captions — *An ordinary push — it stays on its feet* / 平常推一把：没倒, *Pushed over, then recovers to the nominal stance* / 被推倒后自己站回标称姿态, *The hardest case: repeated attempts, finally gets up* / 最剧烈的一段：连续尝试、最终成功起身 — beside the evidence already on that page (40.5 N push threshold; 5/5 end-to-end trials in the strict nominal stance with 4/5 that did not fall again), and placed one GIF plus links to the capability page and the full-length video in both READMEs. / 把三段动图按已确认的双语标题嵌进能力页，并紧挨该页已有的实测依据（抗推临界 40.5 N；端到端 5/5 落在严格标称站姿，其中"起身后没有再次摔倒"4/5），同时在中英文首页各放一段动图，并链接能力页与全长录像。
- Updated [assets/README.md](assets/README.md) with a per-clip note and the simulation scope, and [assets/media-manifest.json](assets/media-manifest.json) with the SHA-256, byte size, dimensions, frame count, duration, and scope note of each new file. / 更新[演示说明](assets/README.md)（逐段说明并写明仿真口径）与[媒体清单](assets/media-manifest.json)（四个新资源的 SHA-256、字节数、尺寸、帧数、时长与 scope_note）。

### 2026-09-16 — Measured capability summary and the standing criterion / 实测能力清单与站位判定口径

- Added [measured capabilities](docs/capabilities.md) / [实测能力清单](docs/capabilities.zh-CN.md): one honest board of the six trained policies (standing against pushes, knock-down recovery, get-up, walking, 1 cm rough terrain, sit/stand), each with its policy, its measured numbers, and the internal tool that produced them. Every figure is copied from a 2026-09-16 measurement log; no figure is extrapolated. / 新增[实测能力清单](docs/capabilities.zh-CN.md)与[英文版](docs/capabilities.md)：把六项训练能力（站立抗扰、推倒恢复、起身、行走、1 cm 越障、坐／站）逐项列出策略、实测数字与产出它的内部工具。所有数字逐条抄自 2026-09-16 的测量日志，没有外推。
- Recorded the measured results: push threshold **40.5 N** (40 N topples 45.3 %, 0 to 24 N topples nothing) and 40 s steady-state drift **0.00 mm/s**; knock-down → get-up → nominal stance **5/5** end-to-end, with "did not fall again after standing up" **4/5**; get-up standing at the end **64/64** while the strict nominal criterion remains **0/64**; 1 cm terrain survival **51/64 (79.7 %)** at **61 %** of the commanded speed. / 记录实测结果：抗推临界 **40.5 N**（40 N 时倒 45.3 %，0–24 N 全不倒）与 40 s 稳态漂移 **0.00 mm/s**；推倒→起身→标称站姿端到端 **5/5**，"起身后没有再次摔倒" **4/5**；起身末态站住 **64/64**，而严格标称口径仍是 **0/64**；1 cm 地形存活 **51/64（79.7 %）**，平均速度是指令的 **61 %**。
- Documented the negative results with the same weight as the positive ones: side-stepping answers a +0.30 m/s command with +0.218 m/s plus **+520.4 deg** of uncommanded yaw, in-place turning produces **+0.3 deg** in 10 s, and the shipped walking checkpoint was trained under a command range that makes it incomparable with the newest table. / 负面结果与正面结果同等写入：侧移对 +0.30 m/s 的指令只回 **+0.218 m/s** 并伴随 **+520.4°** 的未指令自转，原地转 10 s 只转 **+0.3°**，且已 SHIP 的行走检查点训练时用的命令范围与最新一张表不可比。
- Documented how "standing" is judged: tilt below 8 degrees, both soles in contact, every joint within 20 degrees of nominal, base height above 0.15 m, plus a duration rule that the criterion hold for at least **90 % of the last 1.0 s**. On the same final states, demanding all 50 steps gives 20/64 where the final frame alone gives 63 to 64/64. The get-up delivery criterion adds two axes: the head chain must not press the ground (below 2 N) and the soles must be flat (within 5 degrees). / 写明"站稳"的判定口径：倾角 < 8°、双脚着地、每关节偏差 < 20°、基座高度 > 0.15 m，外加"末 1.0 s 里至少 **90 %** 的时刻成立"的持续规则。同一批末态下，要求 50 步全部合格给 20/64，只看末帧给 63–64/64。起身交付口径另加两条：头链不压地（低于 2 N）与双脚平贴（偏差 < 5°）。
- Recorded two structural facts with their evidence: the head chain is **1.654 kg = 44.1 %** of the published model's 3.751 kg, and the maximum static gravity torque about `neck_pitch` is **1.61 N·m** in the training model (**1.574 N·m** recomputed on the published URDF). The published URDF is unaffected — its effort column keeps the rated 0.6 N·m and declares no actuators. / 记录两条带证据的结构性事实：头链占公开模型 3.751 kg 中的 **1.654 kg = 44.1 %**；绕 `neck_pitch` 轴的最大静态重力矩在训练模型上是 **1.61 N·m**（在公开 URDF 上重算为 **1.574 N·m**）。公开 URDF 不受影响：其 effort 列仍保留额定的 0.6 N·m 且不声明任何执行器。
- Updated both READMEs (Development progress and At a glance, each linking the new page), the [roadmap](docs/roadmap.md) with a measured known-gaps section, and this changelog. / 更新中英文首页（开发进度与模型概览两节，并链接新页面）、[路线图](docs/roadmap.md)（新增"已知不足（已实测）"一节）与本更新记录。

### 2026-09-14 — Printable standing fixture and reproduction index / 站姿打印工装与复现入口

- Curated the maintainer's updated P01 and matching H2D project into [standing-zero](hardware/fixtures/standing-zero/README.md): four STEP solids, four millimeter STL files, and a two-plate PLA 3MF with each part required once. / 将维护者优化后的 P01 与匹配 H2D 工程整理到[站姿工装目录](hardware/fixtures/standing-zero/README.zh-CN.md)：四个 STEP 实体、四个毫米 STL、各件一份的双盘 PLA 3MF。
- Added part quantities, six M3 screw specifications, 0.4 mm total fit clearance, assembly/calibration instructions, current CAD/mesh checks, and hashes. Preserved the user's slicer settings and local native master files. Physical fit and repeatability remain unmeasured. / 补充数量表、六颗 M3 螺钉规格、0.4 mm 总配合间隙、装配标定方法及新版 CAD／网格检查和哈希；保留用户切片设置与本地原生工作文件，实物配合及重复定位精度待测。
- Classified 20 robot STEP models into 15 structural types and five purchased-component reference types. Distinguished print geometry from meter-based URDF visualization meshes. / 将 20 个机器人 STEP 模型分为 15 类结构几何与五类采购件参考，区分打印几何与米制 URDF 显示网格。
- Integrated the separate task's [160 mm static A1 mini model](hardware/printable/README.md), print project, generation scripts, and portable slicing report into the print index. / 将另一任务完成的 [160 mm A1 mini 固定展示模型](hardware/printable/README.md)、打印工程、生成脚本和可移植切片报告纳入打印入口。
- Retained the existing MATLAB implementation and trajectory data; clarified its smoke-test scope and distinguished CSV-computed values from unpublished planner reports and physical measurements. / 保留原 MATLAB 实现与轨迹数据，说明快速自检的范围，并区分 CSV 可复核数值、未公开规划器报告与实物测量。

### 2026-09-14 — Motor mass updated to a measurement / 电机质量改用实测值

- The 15 motor instances now use the maintainer-measured **141 g** instead of the 150 g transcribed from the vendor parameter image. Model total mass **3.886339783 → 3.751339783 kg**. / 15 个电机实例改用维护者实测的 **141 g**（原为厂家参数图转录的 150 g），模型总质量 **3.886339783 → 3.751339783 kg**。
- Because motor centers of mass are retained and motor inertias are rescaled by mass ratio, every link that carries a motor changed slightly in mass, center of mass, and inertia. Link geometry, joint definitions, and the zero-pose envelope are unchanged, and the package checks were recomputed from the updated URDF. / 由于电机质心保持不变、惯量按质量比缩放，**每个带电机的 link** 在质量、质心与惯量上都有小幅变化；link 几何、关节定义与零位姿态包络未变，资料包校验项已按更新后的 URDF 重算。
- `motor_parameters.json` now records the basis and date of the mass value, lists the 3.6 N·m peak alongside the 3.7 N·m stall figure, and records a bench observation that the motor held **3.5 N·m for more than 30 s** — labelled as one observation, not a duty-cycle or thermal rating, and with the rated 0.6 N·m left unchanged. / `motor_parameters.json` 现在记录了质量数值的来源与日期、把 3.6 N·m 峰值与 3.7 N·m 堵转并列，并记录了一条台架观测：电机**持续输出 3.5 N·m 超过 30 s**；该条明确标注为单次观测、不是占空比或热额定值，额定 0.6 N·m 不变。
- `component_mass_audit.csv` and `validation.json` were regenerated; the audit's mass column sums to the URDF model mass to within 1e-9 kg, and both manifests carry the new hashes. / 重新生成了 `component_mass_audit.csv` 与 `validation.json`；台账质量列合计与 URDF 模型质量相差 1e-9 kg 以内，两份清单已更新为新哈希。

### 2026-09-14 — Reference gait, MATLAB player, and gait media / 参考步态、MATLAB 回放器与步态媒体

- Added a walking reference trajectory for the published URDF: one steady-state gait cycle (2.0 s, 100 frames at 50 Hz) and the full 1 m walk (104 s at 10 Hz), with joint angles in radians, inverse-dynamics torque estimates, and the body pose. / 新增针对公开 URDF 的行走参考轨迹：一个稳态步态周期（2.0 s，50 Hz 共 100 帧）与整段 1 m 行走（104 s，10 Hz），含弧度制关节角、逆动力学力矩估计与机体位姿。
- Added `tools/matlab/wamoduck_play.m`: an interactive MATLAB player with a per-joint angle/torque table, a torque plot against the motor's rated and peak values, two data sets, and a self-test that checks units, joint limits, and ground contact. / 新增 `tools/matlab/wamoduck_play.m`：交互回放器，含逐关节角度／力矩表、与电机额定／峰值对照的力矩曲线、两份数据，以及检查单位、关节限位与脚底贴地的自检。
- Added gait media rendered from the public URDF: a seamless two-cycle GIF, a 20 s walk video, a still frame, and a screenshot of the MATLAB player. / 新增由公开 URDF 渲染的步态媒体：无缝两周期 GIF、20 s 行走视频、单帧静图，以及 MATLAB 回放器截图。
- Added the [gait guide](docs/matlab.en.md) / [步态指南](docs/matlab.zh-CN.md) in both languages, covering the data format, the scope of the plan, and the measured limits of this leg design: there is no ankle-roll joint, and a single-support step would need at least 57 mm of lateral centre-of-mass travel. / 新增中英文[步态指南](docs/matlab.zh-CN.md)，说明数据格式、规划口径，以及这条腿**实测**出来的限制：没有踝侧摆关节，单脚支撑至少需要 57 mm 的重心横移。
- The gait is a kinematic inverse-kinematics plan with a static-stability check. It is not a trained policy, not hardware data, and not a dynamic-balance result; the media manifest records this scope per asset. / 该步态是带静态稳定性检查的逆运动学规划，不是训练策略、不是实物数据、也不是动态平衡结果；媒体清单按条目记录了该口径。

### 2026-09-12 — Project overview and motion preview / 项目介绍与运动演示

- Highlighted servo closed-loop control, the MCU/Arm architecture, local vision, and mechanical extensibility in both READMEs. / 中英文首页突出伺服闭环、MCU／Arm 架构、本地视觉和结构扩展性。
- Updated project progress: mechanical prototyping, hardware/software integration, completed MuJoCo simulation, the ONNX deployment approach, and experiments with wearable robots. / 更新结构打样、软硬件联调、已完成 MuJoCo 仿真、ONNX 部署方式及穿戴机器人实验应用等进展。
- Added an actual URDF joint-motion GIF and the finalized export's 15-DOF overview. / 新增由实际 URDF 生成的关节运动 GIF，以及最终导出的 15 自由度总览。
- Distinguished project development progress from code and models already published in this repository. / 区分项目研发进展与本仓库已经公开的代码、模型范围。

### 2026-09-12 — Initial mechanical package / 首次机械资料整理

- Added English and Chinese project introductions, mechanical/model guides, a component inventory, and a roadmap. / 新增中英文项目介绍、机械／模型指南、组件清单与路线图。
- Selected 20 STEP models and 31 native SolidWorks files from the simplified design set. / 从简化设计中选入 20 个 STEP 与 31 个 SolidWorks 原生文件。
- Included the 15-DOF URDF, 20 meshes, and model parameter records. / 纳入 15 自由度 URDF、20 个网格与模型参数记录。
- Added asset hashes and package validation evidence. / 补充资产哈希与资料包验证记录。

This entry describes local preparation; no GitHub release is implied. / 本条记录描述本地整理，不表示已在 GitHub 发布版本。

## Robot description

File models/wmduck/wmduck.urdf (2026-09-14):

<?xml version='1.0' encoding='utf-8'?>
<robot name="wmduck">
  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
  <mujoco>
    <compiler discardvisual="false" fusestatic="false" strippath="false" balanceinertia="false" />
  </mujoco>
  <link name="base_link">
    <inertial>
      <origin xyz="-0.0307961905028 -0.000125120788611 -0.0249611043348" rpy="0 0 0" />
      <mass value="0.65064023518" />
      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
    </inertial>
    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
  </link>
  <link name="left_hip_yaw_link">
    <inertial>
      <origin xyz="-0.00132455934023 -9.00048888197e-09 -0.0257363917356" rpy="0 0 0" />
      <mass value="0.151466330426" />
      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
    </inertial>
    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
  </link>
  <link name="right_hip_yaw_link">
    <inertial>
      <origin xyz="-0.00132455934023 -9.00048880911e-09 -0.0257363917356" rpy="0 0 0" />
      <mass value="0.151466330426" />
      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
    </inertial>
    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
  </link>
  <link name="left_hip_roll_link">
    <inertial>
      <origin xyz="-0.00264458890281 0.0195384545424 -3.29347868422e-10" rpy="0 0 0" />
      <mass value="0.0245500285629" />
      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
    </inertial>
    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
  </link>
  <link name="right_hip_roll_link">
    <inertial>
      <origin xyz="-0.00264458890275 -0.0195384545426 -2.77692355222e-10" rpy="0 0 0" />
      <mass value="0.024550028563" />
      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
    </inertial>
    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
  </link>
  <link name="left_hip_pitch_link">
    <inertial>
      <origin xyz="-0.0123743686711 0.0187398257483 -0.0123743686708" rpy="0 0 0" />
      <mass value="0.309377727974" />
      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
    </inertial>
    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
  </link>
  <link name="right_hip_pitch_link">
    <inertial>
      <origin xyz="-0.0123743686708 -0.0187398257483 -0.0123743686711" rpy="0 0 0" />
      <mass value="0.309377727974" />
      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
    </inertial>
    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
  </link>
  <link name="left_knee_link">
    <inertial>
      <origin xyz="0.0113120991116 -0.00769273462022 -0.0195931304015" rpy="0 0 0" />
      <mass value="0.0210816115943" />
      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
    </inertial>
    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
  </link>
  <link name="right_knee_link">
    <inertial>
      <origin xyz="0.0113120991116 0.00769273462022 -0.0195931304015" rpy="0 0 0" />
      <mass value="0.0210816115943" />
      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
    </inertial>
    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
  </link>
  <link name="left_ankle_link">
    <inertial>
      <origin xyz="0.000630945499042 0.0202309539032 -0.00780159554866" rpy="0 0 0" />
      <mass value="0.216671675043" />
      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
    </inertial>
    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
  </link>
  <link name="right_ankle_link">
    <inertial>
      <origin xyz="0.000630945504584 -0.0202309542324 -0.00780159554912" rpy="0 0 0" />
      <mass value="0.216671675042" />
      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
    </inertial>
    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
  </link>
  <link name="neck_pitch_link">
    <inertial>
      <origin xyz="-0.00874999999713 0.0200960457546 0.015155444577" rpy="0 0 0" />
      <mass value="0.327409232363" />
      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
    </inertial>
    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
  </link>
  <link name="head_pitch_link">
    <inertial>
      <origin xyz="-9.54326473575e-09 0.0181719573854 0.0162856278805" rpy="0 0 0" />
      <mass value="0.0367853906427" />
      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
    </inertial>
    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
  </link>
  <link name="head_yaw_link">
    <inertial>
      <origin xyz="-0.00116360826439 -9.00049579258e-09 0.0189530005846" rpy="0 0 0" />
      <mass value="0.151466330426" />
      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
    </inertial>
    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
  </link>
  <link name="head_roll_link">
    <inertial>
      <origin xyz="0.0427980199763 0.000121919021815 0.0367791736582" rpy="0 0 0" />
      <mass value="1.08084048193" />
      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
    </inertial>
    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
  </link>
  <link name="mouth_link">
    <inertial>
      <origin xyz="0.0347912024524 -0.0129994761368 -0.000272678311701" rpy="0 0 0" />
      <mass value="0.0579033656106" />
      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
    </inertial>
    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
  </link>
  <joint name="left_hip_yaw" type="revolute">
    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
    <parent link="base_link" />
    <child link="left_hip_yaw_link" />
    <origin xyz="-0.00889850082397 0.026 -0.04470398" rpy="0 0 0" />
    <axis xyz="0 0 1" />
    <limit effort="0.6" velocity="6.28318530718" lower="-1.72787595947" upper="0.532325421858" />
  </joint>
  <joint name="right_hip_yaw" type="revolute">
    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
    <parent link="base_link" />
    <child link="right_hip_yaw_link" />
    <origin xyz="-0.00889850082397 -0.026 -0.04470398" rpy="0 0 0" />
    <axis xyz="0 0 1" />
    <limit effort="0.6" velocity="6.28318530718" lower="-0.532325421858" upper="1.72787595947" />
  </joint>
  <joint name="left_hip_roll" type="revolute">
    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
    <parent link="left_hip_yaw_link" />
    <child link="left_hip_roll_link" />
    <origin xyz="0.0166025 0 -0.0269" rpy="0 0 0" />
    <axis xyz="1 0 0" />
    <limit effort="0.6" velocity="6.28318530718" lower="-1.11526539202" upper="0.431096325243" />
  </joint>
  <joint name="right_hip_roll" type="revolute">
    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
    <parent link="right_hip_yaw_link" />
    <child link="right_hip_roll_link" />
    <origin xyz="0.0166025 0 -0.0269" rpy="0 0 0" />
    <axis xyz="1 0 0" />
    <limit effort="0.6" velocity="6.28318530718" lower="-0.431096325243" upper="1.11526539202" />
  </joint>
  <joint name="left_hip_pitch" type="revolute">
    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
    <parent link="left_hip_roll_link" />
    <child link="left_hip_pitch_link" />
    <origin xyz="-0.0166 0.0416 0" rpy="0 0 0" />
    <axis xyz="0 1 0" />
    <limit effort="0.6" velocity="6.28318530718" lower="-1.13097335529" upper="2.80474410795" />
  </joint>
  <joint name="right_hip_pitch" type="revolute">
    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
    <parent link="right_hip_roll_link" />
    <child link="right_hip_pitch_link" />
    <origin xyz="-0.0166 -0.0416 0" rpy="0 0 0" />
    <axis xyz="0 1 0" />
    <limit effort="0.6" velocity="6.28318530718" lower="-1.13097335529" upper="2.80474410795" />
  </joint>
  <joint name="left_knee" type="revolute">
    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
    <parent link="left_hip_pitch_link" />
    <child link="left_knee_link" />
    <origin xyz="-0.0247487373415 0 -0.0247487373415" rpy="0 0 0" />
    <axis xyz="0 1 0" />
    <limit effort="0.6" velocity="6.28318530718" lower="-0.574213323906" upper="3.10668606855" />
  </joint>
  <joint name="right_knee" type="revolute">
    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
    <parent link="right_hip_pitch_link" />
    <child link="right_knee_link" />
    <origin xyz="-0.0247487373415 0 -0.0247487373415" rpy="0 0 0" />
    <axis xyz="0 1 0" />
    <limit effort="0.6" velocity="6.28318530718" lower="-0.574213323906" upper="3.10668606855" />
  </joint>
  <joint name="left_ankle" type="revolute">
    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
    <parent link="left_knee_link" />
    <child link="left_ankle_link" />
    <origin xyz="0.027 -0.0046 -0.0467653718044" rpy="0 0 0" />
    <axis xyz="0 1 0" />
    <limit effort="0.6" velocity="6.28318530718" lower="-1.76452787377" upper="0.984365698125" />
  </joint>
  <joint name="right_ankle" type="revolute">
    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
    <parent link="right_knee_link" />
    <child link="right_ankle_link" />
    <origin xyz="0.027 0.0046 -0.0467653718044" rpy="0 0 0" />
    <axis xyz="0 1 0" />
    <limit effort="0.6" velocity="6.28318530718" lower="-1.76452787377" upper="0.984365698125" />
  </joint>
  <joint name="neck_pitch" type="revolute">
    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
    <parent link="base_link" />
    <child link="neck_pitch_link" />
    <origin xyz="0.00460149917603 -0.0186000000001 0.03039852" rpy="0 0 0" />
    <axis xyz="0 1 0" />
    <limit effort="0.6" velocity="6.28318530718" lower="-0.61261056745" upper="2.24274808881" />
  </joint>
  <joint name="head_pitch" type="revolute">
    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
    <parent link="neck_pitch_link" />
    <child link="head_pitch_link" />
    <origin xyz="-0.0175 0 0.0303108891325" rpy="0 0 0" />
    <axis xyz="0 1 0" />
    <limit effort="0.6" velocity="6.28318530718" lower="-1.12748269679" upper="1.20776784238" />
  </joint>
  <joint name="head_yaw" type="revolute">
    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
    <parent link="head_pitch_link" />
    <child link="head_yaw_link" />
    <origin xyz="0 0.0186 0.0374" rpy="0 0 0" />
    <axis xyz="0 0 1" />
    <limit effort="0.6" velocity="6.28318530718" lower="-3.10668606855" upper="3.10668606855" />
  </joint>
  <joint name="head_roll" type="revolute">
    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
    <parent link="head_yaw_link" />
    <child link="head_roll_link" />
    <origin xyz="-0.0269 0 0.0206025" rpy="0 0 0" />
    <axis xyz="1 0 0" />
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

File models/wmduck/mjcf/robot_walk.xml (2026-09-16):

<mujoco model="wmduck_walk">
  <compiler angle="radian" autolimits="true" meshdir=".." discardvisual="false" fusestatic="false" balanceinertia="false"/>
  <option timestep="0.005" integrator="implicitfast" solver="Newton" iterations="30" ls_iterations="50" tolerance="1e-8" cone="pyramidal" impratio="1.0"/>
  <default>
    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
    <default class="visual">
      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
    </default>
    <default class="collision">
      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
    </default>
    <default class="foot">
      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
    </default>
  </default>
  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
  <worldbody>
    <body name="base_link" pos="0 0 0" quat="1 0 0 0">
      <freejoint name="floating_base"/>
      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
      <inertial pos="-0.030796191 -0.000125121 -0.024961104" mass="0.65064023518" fullinertia="0.000767013657234 0.000877740696996 0.000874928102505 2.51539808736e-06 -6.3368463925e-05 3.21785201764e-06"/>
      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
      <body name="left_hip_yaw_link" pos="-0.008898501 0.026 -0.04470398" quat="1 0 0 0">
        <joint name="left_hip_yaw" type="hinge" axis="0 0 1" range="-1.72787596 0.532325422" limited="true" armature="0.001" damping="0.05" frictionloss="0.02"/>
        <inertial pos="-0.001324559 -0.000000009 -0.025736392" mass="0.151466330426" fullinertia="3.28308619931e-05 3.43027633729e-05 3.10679302198e-05 0 -4.95248655672e-07 1.90120876212e-11"/>
        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
        <body name="left_hip_roll_link" pos="0.0166025 0 -0.0269" quat="1 0 0 0">
          <joint name="left_hip_roll" type="hinge" axis="1 0 0" range="-1.11526539 0.431096325" limited="true" armature="0.001" damping="0.05" frictionloss="0.02"/>
          <inertial pos="-0.002644589 0.019538455 0" mass="0.0245500285629" fullinertia="8.84110090163e-06 5.53593458725e-06 1.10010680111e-05 3.54264387788e-06 0 0"/>
          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
          <body name="left_hip_pitch_link" pos="-0.0166 0.0416 0" quat="1 0 0 0">
            <joint name="left_hip_pitch" type="hinge" axis="0 1 0" range="-1.13097336 2.80474411" limited="true" armature="0.001" damping="0.05" frictionloss="0.02"/>
            <inertial pos="-0.012374369 0.018739826 -0.012374369" mass="0.309377727974" fullinertia="0.000121934928728 0.000163208922433 0.000121934928614 0 -4.74616079245e-05 0"/>
            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
            <body name="left_knee_link" pos="-0.024748737 0 -0.024748737" quat="1 0 0 0">
              <joint name="left_knee" type="hinge" axis="0 1 0" range="-0.574213324 3.10668607" limited="true" armature="0.001" damping="0.05" frictionloss="0.02"/>
              <inertial pos="0.011312099 -0.007692735 -0.01959313" mass="0.0210816115943" fullinertia="9.82413649977e-06 1.37899798002e-05 4.41801873665e-06 2.59845188064e-07 4.68183531871e-06 -4.50065067829e-07"/>
              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
              <body name="left_ankle_link" pos="0.027 -0.0046 -0.046765372" quat="1 0 0 0">
                <joint name="left_ankle" type="hinge" axis="0 1 0" range="-1.76452787 0.984365698" limited="true" armature="0.001" damping="0.05" frictionloss="0.02"/>
                <inertial pos="0.000630945 0.020230954 -0.007801596" mass="0.216671675043" fullinertia="7.8899551614e-05 9.92879155467e-05 8.38229441463e-05 -1.8751289219e-07 1.19644203131e-06 2.01735939486e-06"/>
                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
              </body>
            </body>
          </body>
        </body>
      </body>
      <body name="right_hip_yaw_link" pos="-0.008898501 -0.026 -0.04470398" quat="1 0 0 0">
        <joint name="right_hip_yaw" type="hinge" axis="0 0 1" range="-0.532325422 1.72787596" limited="true" armature="0.001" damping="0.05" frictionloss="0.02"/>
        <inertial pos="-0.001324559 -0.000000009 -0.025736392" mass="0.151466330426" fullinertia="3.28308619931e-05 3.43027633729e-05 3.10679302198e-05 0 -4.95248655672e-07 1.90120876212e-11"/>
        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
        <body name="right_hip_roll_link" pos="0.0166025 0 -0.0269" quat="1 0 0 0">
          <joint name="right_hip_roll" type="hinge" axis="1 0 0" range="-0.431096325 1.11526539" limited="true" armature="0.001" damping="0.05" frictionloss="0.02"/>
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

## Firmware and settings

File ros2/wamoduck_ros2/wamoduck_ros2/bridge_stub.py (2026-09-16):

#!/usr/bin/env python3
"""Bridge between a byte transport (/dev/ttyS1 or CAN) and ROS topics. **Skeleton + codec.**

    ros2 run wamoduck_ros2 bridge_stub                       # loopback, no hardware needed
    ros2 run wamoduck_ros2 bridge_stub --ros-args -p transport:=serial -p port:=/dev/ttyS1

Division of labour (``docs/16_真机部署方案.md`` §6.5)
----------------------------------------------------
This node is the *only* place that knows the wire format. Everything above it speaks
``wamoduck_msgs/JointTarget`` downwards and ``sensor_msgs/JointState`` / ``sensor_msgs/Imu``
upwards, so swapping UART for CAN-FD changes this node's transport and nothing else. That
separation is the reason the frame codec lives in its own ROS-free module and is the one part
of this package with real unit tests.

Signal flow::

    JointTarget  -> pack CMD (46 B)          -> transport -> cerebellum
    JointState   <- unpack STATE_Q, STATE_DQ <- transport <- cerebellum
    Imu          <- unpack STATE_IMU         <- transport <- cerebellum
    LinkStatus   <- parser counters + status word

What is implemented and verified
--------------------------------
* the complete frame codec: encode/decode for every frame type, CRC16-CCITT-FALSE with its
  known-answer vector, frame-size assertions, int16 saturation, and a resynchronising parser
  with separate resync / bad-length / bad-CRC counters. Covered by
  ``test/test_frame_codec.py``.
* the topic plumbing for the loopback transport, which needs no hardware.

What is NOT implemented and NOT verified
----------------------------------------
* **no hardware has been touched.** The ``serial`` transport opens a pyserial port but has
  never been run against an AT32; the ``can`` transport is not written at all.
* the cerebellum-side protection layer (200 ms HOLD / 1000 ms OFF / 0.35 rad per-frame rate
  limit / limit clamping) is *specified* in the protocol and is **not** reimplemented here:
  per the design it lives in the firmware, and the host must not duplicate it, because two
  watchdogs with different timeouts is worse than one. Only the host-side ESTOP latch and the
  status-word relay exist.
* no watchdog, no diagnostics aggregation, no ``wmduck_safety`` node yet. ``docs/16`` §6.5
  lists it as a separate node and it is a later stage.
"""

from __future__ import annotations

import sys

import rclpy
from rclpy.node import Node
from rclpy.qos import DurabilityPolicy, HistoryPolicy, QoSProfile, ReliabilityPolicy
from sensor_msgs.msg import Imu, JointState
from std_msgs.msg import Bool

from wamoduck_msgs.msg import JointTarget, LinkStatus

from . import frame_codec as fc
from . import model_contract

# State topics: best effort, depth 1. A queued stale state is worse than a dropped one.
STATE_QOS = QoSProfile(
    depth=1,
    history=HistoryPolicy.KEEP_LAST,
    reliability=ReliabilityPolicy.BEST_EFFORT,
    durability=DurabilityPolicy.VOLATILE,
)

COMMAND_QOS = QoSProfile(
    depth=1,
    history=HistoryPolicy.KEEP_LAST,
    reliability=ReliabilityPolicy.RELIABLE,
    durability=DurabilityPolicy.VOLATILE,
)


class LoopbackTransport:
    """In-process transport: whatever is written comes straight back on the next read.

    Exists so that the topic plumbing, the watchdog bookkeeping and the counters can be
    exercised end to end without an AT32 on the bench. It is not a simulator: it does not
    apply gains, gravity or limits, and it echoes the commanded joints back as if the servos
    tracked perfectly. Never read dynamics into what it shows.
    """

    def __init__(self) -> None:
        self._pending = bytearray()
        self._last_cmd = None
        self.open = True
        self.description = 'loopback (echoes CMD back as STATE_Q; not a simulator)'

    def write(self, data: bytes) -> None:
        frames = list(fc.FrameParser().feed(bytes(data)))
        for frame in frames:
            if frame.type == fc.TYPE_CMD:
                self._last_cmd = fc.unpack_cmd(frame.payload)
            elif frame.type == fc.TYPE_ESTOP:
                self._last_cmd = None
            else:
                continue
        if self._last_cmd is not None and frames:
            payload = fc.pack_state_q(
                self._last_cmd['q_target'],
                age_ms=1,
                status=fc.ST_ENABLED | fc.ST_POLICY_MODE,
            )
            self._pending.extend(fc.pack_frame(fc.TYPE_STATE_Q, payload, seq=frames[-1].seq))

    def read(self) -> bytes:
        data = bytes(self._pending)
        self._pending.clear()
        return data

    def close(self) -> None:
        self.open = False


class SerialTransport:
    """UART transport over pyserial.

    Untested against hardware: pyserial is an optional dependency and the AT32 side does not
    exist in this repository. 921600 8N1 is the documented line rate, at which the 106 B
    uplink round is 23 % of the available bandwidth at 200 Hz.
    """

    def __init__(self, port: str, baudrate: int = 921600) -> None:
        try:
            import serial  # noqa: PLC0415 -- optional, only needed on the real link
        except ImportError as exc:
            raise RuntimeError(
                'transport:=serial needs pyserial: pip install pyserial'
            ) from exc
        self._serial = serial.Serial(
            port, baudrate=baudrate, timeout=0.0, bytesize=8, parity='N', stopbits=1
        )
        self._serial.reset_input_buffer()
        self.open = True
        self.description = f'serial {port} @ {baudrate} 8N1 (never exercised against hardware)'

    def write(self, data: bytes) -> None:
        self._serial.write(data)

    def read(self) -> bytes:
        waiting = self._serial.in_waiting
        return self._serial.read(waiting) if waiting else b''

    def close(self) -> None:
        self._serial.close()
        self.open = False


class CanTransport:
    """CAN-FD transport. Not implemented.

    Every frame payload is <= 64 B, so the identical framing fits one frame per CAN message
    with no upper-layer change; only this class would need writing. Left as an explicit gap
    rather than a silently-empty stub, because a bridge that accepts ``transport:=can`` and
    then never moves is worse than one that refuses to start.
    """

    def __init__(self, channel: str = 'can0', bitrate: int = 1_000_000) -> None:
        raise NotImplementedError(
            'the CAN-FD transport is not implemented yet. Payloads are all <= 64 B, so the '
            'framing already fits one CAN-FD message per frame; implement CanTransport '
            '(python-can) and nothing above it changes.'
        )


def make_transport(kind: str, port: str) -> object:
    if kind == 'loopback':
        return LoopbackTransport()
    if kind == 'serial':
        return SerialTransport(port)
    if kind == 'can':
        return CanTransport(port)
    raise ValueError(f'unknown transport {kind!r}; expected loopback, serial or can')


class BridgeStub(Node):
    """Encode JointTarget to frames, decode frames back into JointState/Imu/LinkStatus."""

    def __init__(self) -> None:
        super().__init__('bridge_stub')

        self.declare_parameter('transport', 'loopback')
        self.declare_parameter('port', '/dev/ttyS1')
        self.declare_parameter('target_topic', '/wmduck/joint_target')
        self.declare_parameter('joint_state_topic', '/joint_states')
        self.declare_parameter('imu_topic', '/imu/data')
        self.declare_parameter('status_topic', '/wmduck/link_status')
        self.declare_parameter('estop_topic', '/wmduck/estop')
        self.declare_parameter('read_period_s', 0.002)
        # JointState.header.frame_id. Convention is the base frame the angles are measured
        # against, not the world.
        self.declare_parameter('base_frame', 'base_link')

        kind = str(self.get_parameter('transport').value)
        port = str(self.get_parameter('port').value)
        try:
            self._transport = make_transport(kind, port)
        except (NotImplementedError, RuntimeError, ValueError) as exc:
            # Refuse to start rather than run a bridge that silently moves nothing.
            raise RuntimeError(f'bridge_stub: {exc}') from exc

        self._parser = fc.FrameParser()
        self._seq = 0
        self._rx_frames = 0
        self._tx_frames = 0
        self._latest_status = 0
        self._latest_age_ms = 0
        self._estop_latched = False

        # The cerebellum reports angles and velocities in *separate* frames (STATE_Q at
        # 200 Hz, STATE_DQ at 200 Hz) so that each fits one CAN-FD message and each can be
        # rate-reduced independently. JointState, on the other hand, is consumed position by
        # position by robot_state_publisher, so the latest of each is cached here and
        # republished together rather than emitting half-filled messages.
        self._latest_q: list[float] | None = None
        self._latest_dq: list[float] | None = None

        # The link array order is the contract's joint-tree order, not the URDF document
        # order. The policy action is in joint-tree order too, so "action -> joint" is the
        # identity permutation; keeping the link array in the same order as the action is
        # still what makes that a single, checkable statement rather than two orders to line
        # up separately.
        self._joint_names = list(model_contract.JOINT_ORDER)

        self.create_subscription(
            JointTarget,
            str(self.get_parameter('target_topic').value),
            self._on_target,
            COMMAND_QOS,
        )
        self.create_subscription(
            Bool, str(self.get_parameter('estop_topic').value), self._on_estop, COMMAND_QOS
        )
        self._joint_publisher = self.create_publisher(
            JointState, str(self.get_parameter('joint_state_topic').value), STATE_QOS
        )
        self._imu_publisher = self.create_publisher(
            Imu, str(self.get_parameter('imu_topic').value), STATE_QOS
        )
        self._status_publisher = self.create_publisher(
            LinkStatus, str(self.get_parameter('status_topic').value), STATE_QOS
        )

        period = max(0.0005, float(self.get_parameter('read_period_s').value))
        self.create_timer(period, self._pump_rx)
        self.create_timer(1.0, self._publish_status)

        self.get_logger().info(f'transport       : {self._transport.description}')
        self.get_logger().info(
            f'CMD frame is {fc.CMD_FRAME_LEN} B '
            f'({fc.CMD_PAYLOAD_LEN} B payload + {fc.FRAME_OVERHEAD} B framing); '
            f'q in joint-tree order, int16 mrad (scale {fc.Q_SCALE:g})'
        )
        self.get_logger().info(
            'cerebellum protection (200 ms HOLD / 1000 ms OFF / 0.35 rad per frame) lives in '
            'the firmware and is deliberately NOT duplicated here'
        )
        self.get_logger().warn(
            'SKELETON: no hardware in the loop, no safety node, no CAN transport. '
            'See the module docstring for exactly what is and is not implemented.'
        )

    # -- downlink -----------------------------------------------------------

    def _on_target(self, message: JointTarget) -> None:
        if self._estop_latched:
            self.get_logger().warn('ESTOP latched; dropping targets', throttle_duration_sec=5.0)
            return

        if len(message.q_target_rad) != fc.N_JOINTS:
            self.get_logger().error(
                f'JointTarget has {len(message.q_target_rad)} joints, expected {fc.N_JOINTS}'
            )
            return

        q_ints, saturated = fc.quantise_i16(message.q_target_rad, fc.Q_SCALE)
        if saturated:
            joints = ', '.join(self._joint_names[i] for i in saturated)
            self.get_logger().warn(
                f'q_target saturated at int16 mrad for: {joints} '
                f'(limit {32767 / fc.Q_SCALE:.3f} rad). Saturation clamps; it never wraps.'
            )

        twist = tuple(message.twist) if len(message.twist) == 3 else (0.0, 0.0, 0.0)
        payload = fc.pack_cmd(
            message.q_target_rad,
            mode=message.mode if message.mode else fc.MODE_POLICY,
            twist=twist,
            t_ms=message.t_ms,
            flags=message.flags,
        )
        frame = fc.pack_frame(fc.TYPE_CMD, payload, seq=self._seq)
        self._seq = (self._seq + 1) & 0xFF
        try:
            self._transport.write(frame)
        except Exception as exc:  # pragma: no cover - transport-level failure
            self.get_logger().error(f'transport write failed: {exc}')
            return
        self._tx_frames += 1

    def _on_estop(self, message: Bool) -> None:
        if not message.data:
            self._estop_latched = False
            self.get_logger().warn('ESTOP cleared')
            return
        self._estop_latched = True
        try:
            self._transport.write(fc.pack_estop())
        except Exception as exc:  # pragma: no cover
            self.get_logger().error(f'failed to send ESTOP frame: {exc}')
            return
        self.get_logger().error('ESTOP sent: 6 B empty-payload frame, immediate unload')

    # -- uplink -------------------------------------------------------------

    def _pump_rx(self) -> None:
        try:
            data = self._transport.read()
        except Exception as exc:  # pragma: no cover - transport-level failure
            self.get_logger().error(f'transport read failed: {exc}')
            return
        if not data:
            return
        for frame in self._parser.feed(data):
            self._rx_frames += 1
            if frame.type == fc.TYPE_STATE_Q:
                self._handle_state_q(frame.payload)
            elif frame.type == fc.TYPE_STATE_DQ:
                self._handle_state_dq(frame.payload)
            elif frame.type == fc.TYPE_STATE_IMU:
                self._handle_state_imu(frame.payload)
            elif frame.type == fc.TYPE_EVENT:
                event = fc.unpack_event(frame.payload)
                self.get_logger().warn(f'cerebellum event: {event["name"]} arg={event["arg"]}')
            else:
                self.get_logger().warn(f'unknown frame type 0x{frame.type:02X}')

    def _handle_state_q(self, payload: bytes) -> None:
        """STATE_Q carries the joint angles, which is the frame that drives everything else."""
        state = fc.unpack_state_q(payload)
        self._latest_status = state['status']
        self._latest_age_ms = state['age_ms']
        self._latest_q = list(state['q'])
        self._publish_joint_state()

    def _handle_state_dq(self, payload: bytes) -> None:
        """STATE_DQ carries the joint velocities and does not republish on its own.

        It only refreshes the cached velocity, so the JointState stream keeps one message per
        angle frame instead of doubling the rate with half-populated messages.
        """
        state = fc.unpack_state_dq(payload)
        self._latest_status = state['status']
        self._latest_age_ms = state['age_ms']
        self._latest_dq = list(state['dq'])

    def _publish_joint_state(self) -> None:
        """Publish a complete JointState from the newest cached angle and velocity frames.

        ``velocity`` is only included once a STATE_DQ has actually arrived. A velocity array
        initialised to zero would be indistinguishable from fourteen joints that are genuinely
        stationary, and that difference matters to anything that integrates it.
        """
        message = JointState()
        message.header.stamp = self.get_clock().now().to_msg()
        message.header.frame_id = str(self.get_parameter('base_frame').value)
        message.name = list(self._joint_names)
        message.position = list(self._latest_q) if self._latest_q is not None else []
        if self._latest_dq is not None:
            message.velocity = list(self._latest_dq)
        self._joint_publisher.publish(message)

    def _handle_state_imu(self, payload: bytes) -> None:
        state = fc.unpack_state_imu(payload)
        self._latest_status = state['status']
        self._latest_age_ms = state['age_ms']
        message = Imu()
        message.header.stamp = self.get_clock().now().to_msg()
        message.angular_velocity.x, message.angular_velocity.y, message.angular_velocity.z = state['gyro']
        message.linear_acceleration.x, message.linear_acceleration.y, message.linear_acceleration.z = state['acc']
        w, x, y, z = state['quat_wxyz']
        message.orientation.w, message.orientation.x = w, x
        message.orientation.y, message.orientation.z = y, z
        self._imu_publisher.publish(message)

    def _publish_status(self) -> None:
        message = LinkStatus()
        message.header.stamp = self.get_clock().now().to_msg()
        message.status = self._latest_status & 0xFFFF
        message.age_ms = self._latest_age_ms & 0xFFFF
        message.rx_frames = self._rx_frames
        message.tx_frames = self._tx_frames
        message.resync_bytes = self._parser.resync_bytes
        message.bad_len = self._parser.bad_len
        message.bad_crc = self._parser.bad_crc
        message.transport_open = bool(getattr(self._transport, 'open', False))
        message.estop = self._estop_latched
        self._status_publisher.publish(message)


def main(args=None) -> None:
    rclpy.init(args=args)
    try:
        node = BridgeStub()
    except RuntimeError as exc:
        # Surface the reason on stderr and exit non-zero: a bridge that starts and does
        # nothing is harder to diagnose than one that refuses to start.
        print(f'bridge_stub: {exc}', file=sys.stderr)
        rclpy.shutdown()
        raise SystemExit(2) from exc
    try:
        rclpy.spin(node)
    except KeyboardInterrupt:
        pass
    finally:
        transport = getattr(node, '_transport', None)
        if transport is not None:
            try:
                transport.close()
            except Exception:  # pragma: no cover
                pass
        node.destroy_node()
        if rclpy.ok():
            rclpy.shutdown()


if __name__ == '__main__':
    main()

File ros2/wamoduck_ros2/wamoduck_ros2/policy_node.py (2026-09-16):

#!/usr/bin/env python3
"""50 Hz policy node: observation -> ONNX -> joint target. **Skeleton this stage.**

    ros2 run wamoduck_ros2 policy_node --ros-args -p onnx_path:=<policy.onnx>

STATUS -- read before relying on anything this node prints
----------------------------------------------------------
This node is an interface skeleton, as agreed for this stage of the ROS 2 work. What is
implemented and unit-tested is the *contract*: the observation layout, the command clamp,
the actuator -> joint permutation and the target computation
(``wamoduck_ros2/policy_interface.py``). What is **not** done and not verified:

* no ONNX policy has been loaded or executed on any machine in this ROS 2 tree;
  ``onnxruntime`` is not installed and ``policy_runner.py`` raises a clear error if reached;
* the node therefore never publishes a real ``JointTarget``;
* it has not been run against the real link, the real IMU or real hardware.

Everything below is written against ``deploy/policy_contract.json`` v1 and
``docs/16_真机部署方案.md`` §6.5. The numbers are quoted from those files, not measured here.

THE OBSERVATION / ACTION CONTRACT (frozen, changed only by regenerating the contract)
------------------------------------------------------------------------------------
**51-dimensional observation for the walk tasks**, in ONNX input order::

    base_ang_vel(3) | projected_gravity(3) | joint_pos(14) | joint_vel(14) | last_action(14) | command(3)

with offsets::

    0  base_ang_vel        3   rad/s, IMU gyro, body frame
    3  projected_gravity   3   unit vector, gravity in the body frame; upright is (0, 0, -1)
    6  joint_pos          14   rad; relative to default_joint_pos, which is all zeros, so
                               this is the absolute joint angle
    20 joint_vel          14   rad/s
    34 last_action        14   the previous raw policy output, BEFORE action_scale is applied
    48 command             3   (vx m/s, vy m/s, wz rad/s), clamped to the trained ranges
                               x[-0.6, 1.0]  y[-0.3, 0.3]  wz[-0.8, 0.8]

Total 51. The **stand** policies were trained with **48** inputs: the same layout with the
trailing ``command`` block absent. 48 and 51 are not interchangeable.

**The ONNX graph contains its own normalizer** (``Sub``/``Div``/``Elu``/``Gemm``; the
contract records ``normalizer_inside_onnx: true``). The host therefore feeds **raw**
observations. Normalising again on this side would apply the transform twice -- the classic
way to get a policy that trains well and stands badly.

**The action is 14 wide and in joint-tree order** -- the same order as the observation, not
the MJCF ``<actuator>`` order. ``action_to_joint`` in ``deploy/policy_contract.json``,
mirrored as ``model_contract.ACTION_TO_JOINT``, is still applied exactly once, here, on the
host; it is the identity since the 2026-09-16 adjudication (see the ``model_contract`` module
docstring for the evidence). The firmware only needs to map its own CAN IDs onto the 14 array
slots.

**Target computation**::

    q_target[joint] = default_joint_pos[joint] + action_scale * action[joint]

with ``default_joint_pos`` = all zeros and ``action_scale`` = 1.0 for the current policies,
so in practice ``q_target = action``. It is still written symbolically so a future policy
with a non-zero default does not require editing logic.

**Timing**: control rate **50 Hz**; MuJoCo ``timestep`` = **0.005 s**; ``decimation`` = **4**,
so the policy acts every ``0.005 * 4 = 0.02 s``. 50 Hz and 0.02 s are the same statement and
must stay consistent.

Engineering rules this node must follow (``docs/16`` §6.5)
----------------------------------------------------------
1. **State topics use BEST_EFFORT + KEEP_LAST(1).** With RELIABLE and a queue deeper than
   one, a single slow callback leaves stale observations queued and the policy then reasons
   about tens-of-milliseconds-old state. The symptom is "sluggish and oscillating", and it
   is very hard to find after the fact. Command topics are the opposite: reliable, and
   ``JointTarget`` is published at a fixed 50 Hz so a drop is visible as a sequence gap.
2. **The 50 Hz callback does exactly three things**: take the newest state, infer, publish
   the target. No logging to disk, no parameter service calls, no TF lookups. Logging runs on
   its own timer.
3. **Start-up order matters**: the bridge and the safety side come up first, the policy last.
   A policy that is not ready leaves the cerebellum on its watchdog (HOLD at 200 ms, OFF at
   1000 ms). That is the intended failure mode, not a bug to be designed around.
"""

from __future__ import annotations

import rclpy
from rclpy.node import Node
from rclpy.qos import DurabilityPolicy, HistoryPolicy, QoSProfile, ReliabilityPolicy
from sensor_msgs.msg import Imu, JointState

from wamoduck_msgs.msg import JointTarget

from . import model_contract
from .policy_interface import (
    ObservationState,
    action_to_joint_target,
    assemble_observation,
    joint_state_to_contract_order,
    projected_gravity_from_quat,
)
from .policy_runner import PolicyRunner, PolicyRunnerUnavailable

# State inputs: best effort, depth 1. See rule 1 in the module docstring.
STATE_QOS = QoSProfile(
    depth=1,
    history=HistoryPolicy.KEEP_LAST,
    reliability=ReliabilityPolicy.BEST_EFFORT,
    durability=DurabilityPolicy.VOLATILE,
)

# Command outputs: reliable, depth 1 -- the newest target supersedes the previous one, and a
# gap in the 50 Hz stream is information the other end needs.
COMMAND_QOS = QoSProfile(
    depth=1,
    history=HistoryPolicy.KEEP_LAST,
    reliability=ReliabilityPolicy.RELIABLE,
    durability=DurabilityPolicy.VOLATILE,
)
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

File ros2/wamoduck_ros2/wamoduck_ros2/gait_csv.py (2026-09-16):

"""Reader for the reference gait CSVs under ``tools/matlab/data/``.

File shape
----------
The first line is a ``#`` comment carrying the provenance and the plan parameters. The
second line is the header, and the data starts on the third. Columns are::

    t_s
    q_<joint> ...      15 columns, radians, one per movable URDF joint
    tau_<joint> ...    15 columns, N.m, the plan's feed-forward torque
    base_x, base_y, base_z, base_roll_rad

The joint column names are ``q_<urdf joint name>``, so they are matched **by name** against
the URDF. Nothing in this module assumes a column position, and nothing assumes the URDF
document order or the policy contract order.

What these files are not
------------------------
They are quasi-static kinematic inverse-kinematics plans, not hardware logs and not the
output of a trained policy. ``step_len = 0.01 m`` and ``speed = 0.01 m/s`` for both files.
They are used here to prove that the description animates and that a JointState stream at a
known rate is well formed. A gait that *looks* right in RViz says nothing about whether it
would balance on hardware, because RViz integrates no dynamics at all.
"""

from __future__ import annotations

import csv
import statistics
from bisect import bisect_right
from dataclasses import dataclass, field
from pathlib import Path

_ARRAY_FIELDS = ("base_x", "base_y", "base_z", "base_roll_rad")


@dataclass(frozen=True)
class GaitTrack:
    """One parsed gait CSV."""

    path: str
    comment: str
    times_s: tuple[float, ...]
    """Timestamps made relative to the first sample, so playback always starts at 0."""
    joint_positions: dict[str, tuple[float, ...]] = field(default_factory=dict)
    joint_efforts: dict[str, tuple[float, ...]] = field(default_factory=dict)
    base: dict[str, tuple[float, ...]] = field(default_factory=dict)

    @property
    def samples(self) -> int:
        return len(self.times_s)

    @property
    def duration_s(self) -> float:
        return self.times_s[-1] - self.times_s[0] if self.times_s else 0.0

    @property
    def nominal_hz(self) -> float:
        """Median sample rate. Median, not mean, so one timestamp glitch cannot skew it."""
        if len(self.times_s) < 2:
            return 0.0
        deltas = [b - a for a, b in zip(self.times_s, self.times_s[1:])]
        median = statistics.median(deltas)
        return 1.0 / median if median > 0 else 0.0

    @property
    def uniform(self) -> bool:
        """True when every step is within 1 % of the median step."""
        if len(self.times_s) < 3:
            return True
        deltas = [b - a for a, b in zip(self.times_s, self.times_s[1:])]
        median = statistics.median(deltas)
        if median <= 0:
            return False
        return all(abs(d - median) <= 0.01 * median for d in deltas)

    def index_at(self, t_rel: float) -> int:
        """Index of the newest sample at or before ``t_rel`` (clamped to the track)."""
        if not self.times_s:
            raise ValueError("empty track")
        return max(0, min(self.samples - 1, bisect_right(self.times_s, t_rel) - 1))

    def joint_names(self) -> list[str]:
        return list(self.joint_positions)


def load_gait_csv(path: str | Path) -> GaitTrack:
    """Parse a gait CSV. Raises ``ValueError`` with a readable message on a malformed file."""
    csv_path = Path(path)
    if not csv_path.is_file():
        raise FileNotFoundError(f"gait CSV not found: {csv_path}")

    comments: list[str] = []
    header: list[str] | None = None
    rows: list[list[str]] = []

    with csv_path.open("r", encoding="utf-8", newline="") as handle:
        for raw in handle:
            line = raw.rstrip("\r\n")
            if not line.strip():
                continue
            if line.lstrip().startswith("#"):
                if header is None:
                    comments.append(line.lstrip()[1:].strip())
                continue
            if header is None:
                header = [cell.strip() for cell in next(csv.reader([line]))]
                continue
            rows.append(next(csv.reader([line])))

    if header is None:
        raise ValueError(f"{csv_path}: no header line found")
    if not rows:
        raise ValueError(f"{csv_path}: header found but no data rows")
    if "t_s" not in header:
        raise ValueError(f"{csv_path}: header has no 't_s' column (found {header[:6]}...)")

    columns: dict[str, list[float]] = {name: [] for name in header}
    for line_no, row in enumerate(rows, start=1):
        if len(row) != len(header):
            raise ValueError(
                f"{csv_path}: data row {line_no} has {len(row)} fields, header has {len(header)}"
            )
        for name, cell in zip(header, row):
            try:
                columns[name].append(float(cell))
            except ValueError as exc:
                raise ValueError(
                    f"{csv_path}: data row {line_no}, column '{name}': {cell!r} is not a number"
                ) from exc

    raw_times = columns["t_s"]
    if any(b < a for a, b in zip(raw_times, raw_times[1:])):
        raise ValueError(f"{csv_path}: t_s is not monotonically non-decreasing")
    t0 = raw_times[0]
    times = tuple(t - t0 for t in raw_times)

    joint_positions: dict[str, tuple[float, ...]] = {}
    joint_efforts: dict[str, tuple[float, ...]] = {}
    for name in header:
        if name.startswith("q_"):
            joint_positions[name[2:]] = tuple(columns[name])
        elif name.startswith("tau_"):
            joint_efforts[name[4:]] = tuple(columns[name])

    if not joint_positions:
        raise ValueError(f"{csv_path}: no 'q_<joint>' columns found")

    base = {name: tuple(columns[name]) for name in _ARRAY_FIELDS if name in columns}

    return GaitTrack(
        path=str(csv_path),
        comment=" ".join(comments),
        times_s=times,
        joint_positions=joint_positions,
        joint_efforts=joint_efforts,
        base=base,
    )
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

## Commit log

2026-09-11 Add simplified CAD, URDF, and bilingual docs
    - Add 20 simplified STEP models and 31 native SolidWorks files.
    - Include the 15-DOF URDF, 20 meshes, and model parameter records.
    - Document CAD usage, model assumptions, components, and next steps in
    English and Chinese, with asset hashes and import validation results.
    中文摘要：整理首批简化机械模型、URDF 与中英文项目文档，补充组件清单、
    模型假设、后续计划及文件校验记录。
    [Battery_6s18650_24V.SLDPRT, Battery_6s18650_24V.stl, Battery_6s18650_24V.stp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]
2026-09-11 docs: showcase Wamoduck features and joint motion
2026-09-14 feat: reference gait, MATLAB player, and measured motor mass
    Two changes that belong together: a walking reference gait for the published
    URDF (with a MATLAB player and preview media), and a motor-mass correction that
    brings the model in line with a measurement.
    Reference gait and MATLAB player
    - tools/matlab/wamoduck_play.m: interactive player. Play/pause, advance step,
    switch between two data sets, skeleton or full-mesh view, a torque plot
    against the motor's rated and peak values, and a per-joint table.
    - tools/matlab/data/: one steady-state gait cycle (2.0 s, 100 frames at 50 Hz,
    loops seamlessly) and the full 1 m walk decimated to 10 Hz. Joint angles in
    radians and inverse-dyna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
    [component_mass_audit.csv, gait_cycle_2s_50Hz.csv, gait_walk_1m_10Hz.csv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]
2026-09-14 feat: add printable models and branded project documentation
    Package the updated standing-zero fixture as four STEP solids, four print STL files, and the maintainer's H2D PLA project, with quantities, assembly instructions, and validation records.
    Include the A1 mini display model, slicer project, generation scripts, and portable slicing report. Classify robot structural and purchased-reference geometry, and update the bilingual reproduction guides.
    Add Wamotech logos and contact links to both READMEs. Preserve the existing MATLAB implementation and trajectory data while clarifying the documentation. Exclude local CAD workspaces, duplicate bundles, and slicer intermediates.
    [H2D_PLA_standing_zero.3mf, P01_Main_frame.step, P01_Main_frame.stl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]
2026-09-16 docs: add measured capability summary and standing criterion
    Add docs/capabilities.md plus its Chinese counterpart: one honest board of the
    six trained policies (standing against pushes, knock-down recovery, get-up,
    flat-ground walking, 1 cm rough terrain, sit/stand), each with the policy, the
    measured numbers, and the internal tool that produced them. All figures were
    measured in simulation on 2026-09-16 and are copied from measurement logs.
    Recorded as measured: push threshold 40.5 N and 40 s steady-state drift
    0.00 mm/s; knock-down -> get-up -> nominal stance 5/5 end-to-end, with did not
    fall again after standing up at 4/5; get-up standing at the end 64/64 while the
    strict nominal criter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
2026-09-16 feat: publish five trained policies with the training MJCF and a CPU runner
    Five trained policies are now runnable by an external user with plain MuJoCo:
    * policies/ - ONNX actors for standing (stand_v3/model_1499.pt), get-up
    (getup_v18/model_3999.pt), sit/stand (sit_stand_v2/model_2499.pt), walking
    (walk_v4r/model_6000.pt), and 1 cm rough terrain (rough_v2/model_5999.pt).
    Runs and checkpoints were resolved with run_select.py's rules, and every file
    was confirmed to be the export of exactly that checkpoint by rebuilding the
    actor from the .pt file and comparing it with the ONNX initializers.
    * models/wmduck/mjcf/ - the training-time MJCF (robot_walk.xml,
    robot_groundcontact.xml)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
    [robot_groundcontact.xml, robot_walk.xml]
2026-09-16 feat: switch all five policies inside one simulator demo
    wamoduck_sim.py used to be five separate runs, one policy each. It is now one
    demo: the viewer starts on --policy (stand by default) and switches between
    every published policy while it runs -- 1/2/3/4/5 for
    stand/getup/sitstand/walk/rough, and Tab or n for the next one in that order --
    so walking, sitting down, standing up, and the 1 cm rough terrain are all
    reachable in the same window, without restarting the script.
    * Switching between stand, sitstand, walk, and rough -- the four policies that
    share robot_walk.xml -- keeps the robot state. Only the ONNX actor and the
    observation assembly (48 / 49 / 51 values) are swapped in pla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
2026-09-16 feat: add a ROS 2 Jazzy link for the description, gait replay and the 46-byte protocol
    Adds ros2/ with three packages, and the evidence produced by building and running them
    on WSL2 Ubuntu 24.04 (x86_64) with ROS 2 Jazzy.
    wamoduck_msgs JointTarget, the ROS-side image of the 46 B CMD payload, and
    LinkStatus for the link counters and cerebellum status word
    wamoduck_description URDF + meshes + RViz, both RViz configs and display.launch.py
    wamoduck_ros2 gait_player, policy_node (skeleton), bridge_stub (skeleton + codec)
    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
2026-09-16 feat: show the running and selected policy inside the viewer window
    The window is where the user is looking while pressing 1-5, so the policy name
    belongs there and not only in the terminal. The passive viewer can draw text
    overlays, so the runner now writes two lines:
    top-left policy: walk obs 51-D act 14-D robot_walk.xml terrain: flat
    bottom-left selected: walk (1-5 / Tab / n switches policy) cmd vx +0.30 vy +0.00 wz +0.00
    * "policy" is the policy that is running; "selected" is the one that was last
    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
2026-09-16 docs: record the two reported sitstand problems, measured on CPU
    A user playing the published demo reported that the sit/stand policy buzzes in
    place while standing, and that sitting down does not give the pose they
    described as "head and torso vertical to the ground, left and right legs braced
    symmetrically". Both were measured afterwards with the published single-file
    runner, CPU only (MuJoCo 3.10.0 / ONNX Runtime 1.30.0 / NumPy 2.5.3), 500
    control steps (10.0 s) per run, spawn nominal, flat floor, on the documented
    command path:
    python wamoduck_sim.py --policy sitstand --target-height 0.175 --headless --steps 500
    python wamoduck_sim.py --policy sitstand --target-height 0.085 --headle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
2026-09-16 feat: publish the CAN-FD motor IDs, the three buses, and the action permutation
    Add hardware/motor_ids.csv and hardware/motor_ids.json with an English and a
    Chinese guide beside them, plus the motor position drawing as
    assets/wamoduck-motor-ids.png. The table gives the bus ID of each of the 15
    motors, the joint it drives, the physical bus it sits on, and whether a
    published policy drives it.
    This is hardware and interface information, not a performance claim. Nothing
    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
    [motor_ids.csv, motor_ids.json]
2026-09-16 fix(ros2): the action order is joint-tree order - adjudicate and correct the contract
    The repository contradicted itself: wamoduck_sim.py reads the 14-wide policy output in
    joint-tree order while ros2/.../model_contract.py read it in actuator (MJCF <actuator>)
    order. The two disagree for action[1] to action[8], so exactly one could be right. It is
    joint-tree order; the ROS 2 side is corrected, not the runner. ACTION_TO_JOINT is now the
    identity.
    Adjudicated on four independent lines of evidence:
    1. Source semantics. mjlab's Entity.find_joints_by_actuator_names filters the joint list in
    tree order and its resolve_matching_names(..., preserve_order=False) call returns in that
    order; Ba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
    [motor_ids.json]
2026-09-16 fix(policies): republish the walking policy from its run's final checkpoint
    The published `wamoduck-walk-walk_v4r.onnx` was copied out of the run directory
    `2026-09-16_12-01-21_walk_v4r` while that run was still training. mjlab rewrites
    that directory's ONNX on every checkpoint save (velocity runner: super().save()
    and then export_policy_to_onnx() into the same path), so the copy captured the
    save that wrote model_6000.pt at 14:42:16, and the run's final save,
    model_6749.pt at 15:10:28, overwrote the file locally afterwards and never
    reached this repository.
    Both files are valid exports of the same run. The published one is now the run's
    final checkpoint, which is also the checkpoint the de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
2026-09-16 docs: state why in-place turning cannot be trained away, and correct the walk checkpoint
    The capability board listed in-place turning as an unfinished item, which implies
    another training round would fix it. It would not. A new subsection
    (docs/capabilities.md / .zh-CN.md, "Why in-place turning cannot be trained away")
    reports three binding constraints, each with an analytic bound and a measured
    value from the same scene:
    * the hips' yaw joints are an internal torque pair (net moment zero), so with
    both feet planted they twist the torso only +-30.5 deg relative to the
    ground -- measured 8.0 deg of foot slip plus 22.5 deg of torso = 30.5 deg;
    * unloading one foot needs a 59.8-60.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
2026-09-16 docs: replace the commanded arc ratio with a measured arc radius, and measure the low-speed dead zone
    The previous commit called "R = vx/|wz| ~ 0.40 m" the tightest measured arc. That
    is the commanded ratio, not a measurement, and "0.15 m/s gives 0.00 deg/s of yaw"
    was a figure I could not source. Both are now replaced with numbers measured
    first-hand through the published runner on CPU (10 s runs, yaw command 0.5 rad/s =
    28.6 deg/s, yaw integrated step by step, and a wz = 0 control at every speed so
    that "did not turn" cannot be confused with "did not move"):
    vx 0.10, wz 0.5 : travelled 0.012 m in 10 s, yaw 0.00 deg/s
    vx 0.15, wz 0.5 : travelled 0.018 m in 10 s, yaw 0.00 deg/s
    vx 0.2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
2026-09-16 feat(policies): replace the sit/stand policy; both reported problems are fixed
    `sit_stand_v3` replaces `sit_stand_v2` as the published sit/stand policy. Measured
    on CPU by the development repository's seven-axis acceptance tool, against the
    same tool's numbers for the old file:
    standing jitter mean|da| 0.699 -> 0.000 rad
    net drift +27.99 -> +0.394 mm/s
    sitting tilt (0.112 m) 10.05 -> 0.225 deg
    left/right residual 146.09 -> 0.473 deg
    both feet + CoM inside ... -> 100 % of the last second
    The seat moves from 0.085 m to 0.11241 m because 0.085 m is geometrically
    unreachable with an upright trunk: the torso collision box's lowest corner is
    109 m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
2026-09-16 feat(policies): replace the get-up policy; it now returns to the nominal stance
    `getup_v20` replaces `getup_v18` as the published get-up policy and closes the gap
    this repository measured on the old one. Measured by the development repository's
    three acceptance tools, all against the same protocol as the old numbers:
    standing at the end, random lying pose 64/64 (unchanged)
    strict "back to the saved nominal pose" 0/64 -> 63/64 (98.4 %)
    largest joint deviation 52.3 -> 10.4 deg
    median time to first standing 0.48 s
    final tilt (mean) 2.5 deg
    end-to-end hand-over 5/5, and 5/5 "did not fall again"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
2026-09-16 docs(getup): record that the 'both feet' acceptance axis under-counts
    The six-axis get-up acceptance reads 'both feet on the ground' through
    stand_criteria, whose foot-contact path this project has already flagged as
    unreliable (it infers contact counts from nacon[0], a per-world array). The same
    acceptance run cross-checks it against the contact sensors and finds 60/64 on that
    path against 64/64 from the sensors, so the axis is biased low. Recorded on the
    capability board in both languages and in the policies table; the two axes added
    for head clearance and sole flatness do not use that path.
    No number changed: this is a caveat on an existing one.
2026-09-16 docs(rough): add the flat-ground control the rough-terrain row was missing
    The capability board's rough-terrain row said no flat-ground control run was made,
    so the 61 % speed loss could not be attributed to the terrain alone. Running the
    published policy in the bundled runner on CPU (600 control steps = 12 s,
    vx = +0.30 m/s, commanded 3.600 m) gives +3.458 m (96.1 %) on a flat floor and
    +3.316 m (92.1 %) over 3 consecutive 1 cm curbs -- about 4 percentage points, not
    39.
    That does not overturn the 61 %: that figure is from the development repository's
    generated terrain at difficulty rows 0-5, which is denser and includes step-downs,
    measured in a different simulator under a different proto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
2026-09-16 docs(getup): re-measure the six-axis criterion at 256 environments
    The earlier six-axis figure for getup_v20 was 45/64 (70.3 %), which understates it:
    at 256 environments the same criterion reads 206/256 (80.5 %), with per-axis rates
    of 239/256 (tilt), 221/256 (both feet), 237/256 (joint deviation), 255/256 (base
    height), 253/256 (head off the ground) and 209/256 (flat soles). The per-axis rates
    are the stable part; the all-six conjunction is limited by sample size, so the
    larger run is the better estimate. Means and extremes are unchanged: final tilt
    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
2026-09-17 feat(demo): show what the policy does, and which keys work, in the viewer
    The in-viewer overlay said `policy: sitstand` and `selected: ...`. Both are version
    handles, not descriptions: "sitstand" does not say that `m` is how you use it, and
    neither line said which keys were live at that moment. A reader had to guess both.
    The top-left block is now built from the policy registry and the key table:
    [3/5] 坐下与站起 Sit down and stand up
    sitstand = sit_stand_v3 obs 49-D 平地 flat
    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
2026-09-17 fix(demo): draw the status block as an image, because the HUD font cannot do CJK
    The previous overlay used viewer.set_texts for a four-line bilingual block. Two
    things were wrong with that, and the user's screenshot showed both: MuJoCo's HUD
    font is bitmap ASCII, so every Chinese character came out as a box, and set_texts
    draws all entries that share a gridpos stacked *on top of each other* rather than
    wrapped, so the keys line and the flow line overlapped.
    The top-left block is now rendered with Pillow (system CJK font) into an RGB panel
    and blitted with viewer.set_images, so Chinese renders, lines really wrap, and a
    translucent-looking dark panel keeps it readable over the model. Only the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
